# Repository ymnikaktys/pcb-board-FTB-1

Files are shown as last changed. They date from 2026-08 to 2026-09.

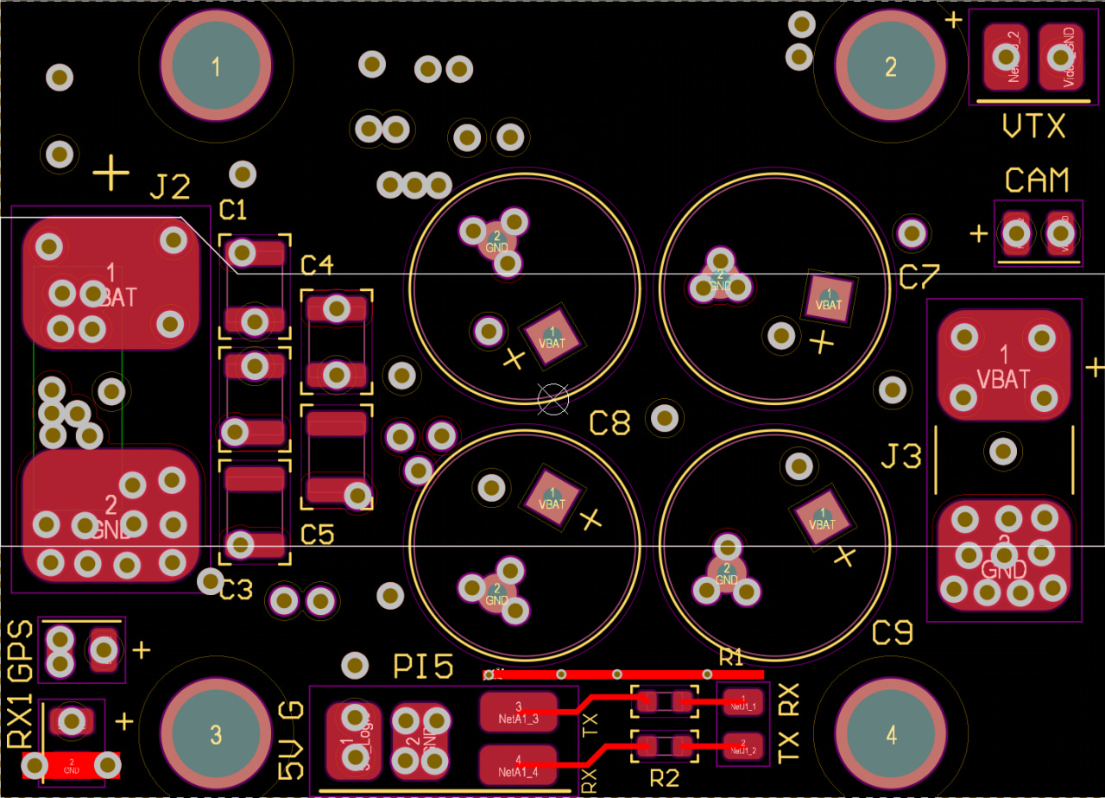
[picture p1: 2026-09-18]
top_layer.png

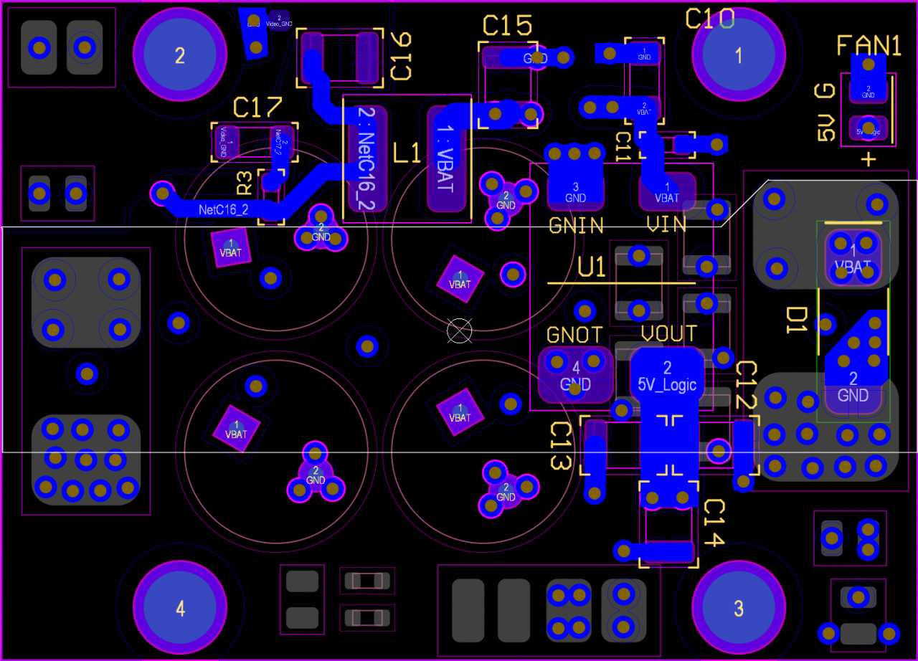
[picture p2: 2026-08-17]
bottom_layer.png

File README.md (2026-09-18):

# High-Power PDB for 7" Experimental Drone Testbed (v1.0)

A custom power distribution board (PDB) with integrated filtering and surge protection, designed for a 7" experimental drone testbed (high-current loads up to 150A) and onboard companion logic.

Developed in Altium Designer. Hardware verification and transient analysis performed in QSPICE.

---

## 🛠 Hardware Specs

* **Copper Topology:** 4-Layer, 2 oz (70 µm) copper stackup with solid ground planes to minimize loop inductance and thermal dissipation on high-current traces.
* **Input Voltage:** 6S Li-Ion / LiPo (25.2V nominal, surge tolerant up to 35V).
* **Power Rail (VBAT / ESC):**
  * Peak Current: up to 150A pulse load.
  * Direct heavy-gauge solder pads for XT90-S (Anti-Spark) input and ESC power lines.
  * Bulk DC-Link: 4x 390 µF Low-ESR electrolytic capacitor array (1560 µF total).
  * High-Frequency Snubbing: 5x 22 µF 1210 MLCC ceramic array directly at the input rail.
* **TVS Protection:**
  * SMCJ26A bidirectional/unidirectional TVS diode clamping inductive spikes and regenerative braking overvoltage below 31.7V.
* **Logic & Peripheral Power Supply:**
  * Dedicated high-current pads for external Hobbywing 5A UBEC (5V_Logic rail).
  * Direct interface headers for **Orange Pi 5 Pro** (AI Companion PC), **Beitian M10 GPS**, and **ELRS Receiver**.
  * Damped series termination resistors (47 Ohm) on MAVLink UART lines for Ground Bounce protection.
* **Analog Video LC Filter:**
  * Shielded inductor (33 µH / 1.5A) + damped multi-stage ceramic filter providing -20 dB attenuation at 24 kHz and -33 dB at 48 kHz PWM switching frequency.
  * Star-ground isolation (`Video_GND`) via Net Tie (`NT1`) dedicated to **Rush Tank Solo 1.6W VTX** and **Caddx Ratel 2** camera.

---

## 📁 Repository Structure

```text
├── Hardware/
│   ├── PDB_Core_6S2P_v1.8.PrjPcb    # Main Altium project
│   ├── PDB_Schematic_v1.8.SchDoc    # Schematic document
│   └── PDB_Layout_2oz_v1.8.PcbDoc   # PCB layout document
├── Libraries/
│   ├── PDB_Components_v1.8.SchLib   # Custom SCH library
│   └── PDB_Footprints_v1.8.PcbLib   # Custom PCB footprint library
├── Manufacturing/
│   └── Gerber_NC_Drill_v1.8.rar     # Production files
├──Simulations/
│   ├── MACRO.qsch                             # Full-system 6S2P power network macro-model & voltage sag analysis
│   ├── ESC_HF_PhaseShift_v1.0.qsch            # High-frequency MOSFET half-bridge inverter, switching ringing & snubber
│   ├── lc_filter_video.qsch                   # AC Bode analysis & PWM ripple attenuation for the video LC filter
│   ├── INRUSH CURRENT no deff.qsch            # Unprotected hot-plug inrush current transient (336A peak surge)
│   ├── INRUSH CURRENT wth deff.qsch           # Soft-start pre-charge simulation modeling XT90-S Anti-Spark behavior (4.5A)
│   ├── Power Integrity — PI.qsch              # 5V digital logic rail stability under pulsed NPU load (YOLOv8 inference)
│   └── Ground_Bounce_on_UART.qsch             # MAVLink telemetry UART Ground Bounce & signal integrity analysis
├── Docs/
│   └── Simulations QSPICE.pdf                 # Full 45-page engineering calculations & simulation report (russion language)
├── top_layer.png                              # Top layer PCB preview image
├── bottom_layer.png                           # Bottom layer PCB preview image
└── README.md

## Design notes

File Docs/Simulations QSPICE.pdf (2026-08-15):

### 1. РАЗДЕЛ 1: МАКРОМОДЕЛЬ БОРТОВОЙ СЕТИ (PDB) И ЦЕПЕЙ

ЗАЩИТЫ В ПЕРЕХОДНЫХ РЕЖИМАХ

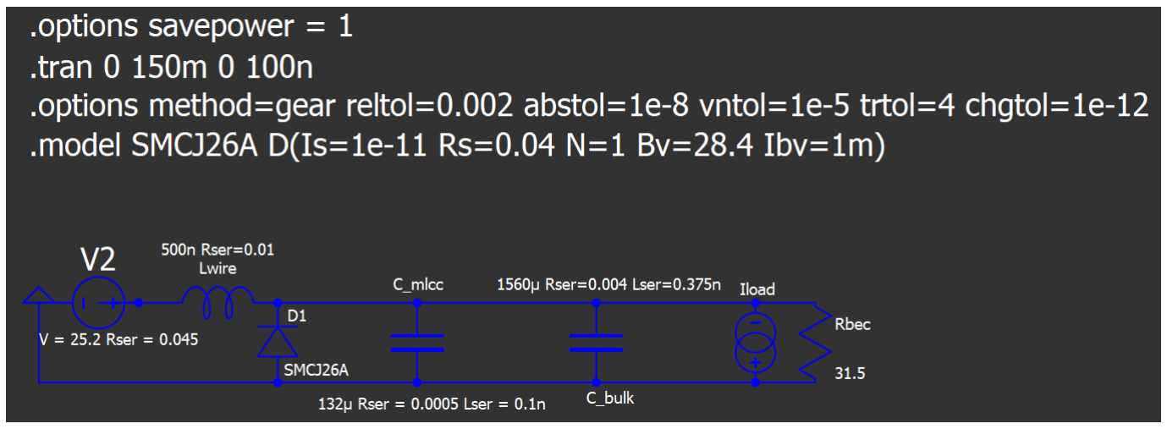
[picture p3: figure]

Конфигурация А: Базовая цепь (6S1P)

Конфигурация Б: Финальная модернизированная цепь (6S2P)

### 1.1 Физические параметры и условия симуляции

Для верификации устойчивости цепей питания цифровой и силовой частей дрона в среде QSPICE была построена сквозная транзиентная макромодель первичного силового контура платы распределения питания (PDB). Исследование проводилось в два этапа для сравнения базовой и модернизированной архитектур:

Конфигурация А: Базовая цепь (6S1P)
- Источник питания: Высокотоковый литий-ионный аккумулятор Lishen LR2170LA в топологии 6S1P (номинальное напряжение пака 25.2 В). Полное эквивалентное внутреннее сопротивление пака (ESR) с учетом соединительных никелевых лент, силовой трассы AWG12 и контактов разъема XT60 задано как Rser = 0.09Ω.
- Линия передачи: Проводник длиной ~12 см с паразитной индуктивностью кабеля Lwire = 0.5 мкГн (500 нГн).

- Фильтр и защита: Локальный буфер из 4-х параллельных электролитических конденсаторов Low-ESR емкостью 390 мкФ (Rser = 0.02Ω, общая емкость 1560 мкФ). Параллельно нагрузке подключен дискретный супрессор (TVS-диод) SMCJ26A со следующими параметрами макромодели: напряжение лавинного пробоя Bv = 28.4 В, динамическое внутреннее сопротивление Rs = 0.04Ω, ток утечки Ibv = 1 мА.
- Профиль динамической нагрузки (Iload): Имитация общего потребления стека ESC импульсным источником тока с функцией PULSE(2 150 10m 10m 2m 50m). Ток покоя — 2 А (арминг), пиковый ток при выходе моторов на 100% газа — 150 А, время нарастания — 10 мс, полка максимального газа — 50 мс, сброс газа/активное торможение — 2 мс.

Конфигурация Б: Финальная модернизированная цепь (6S2P)
- Источник питания: Переход на аккумуляторную сборку типа 6S2P. За счет параллельного удвоения ячеек Lishen внутреннее сопротивление пака снижено ровно в два раза — до Rser = 0.045Ω.
- Модернизированный буферный банк: Интеграция четвертого Low-ESR конденсатора 390 мкФ (Rser = 0.02Ω), что сформировало суммарный емкостный буфер 1560 мкФ. Между банками не учтены паразитные индуктивности печатных проводников PDB из-за сверх широкого силовго полигона на top layer и 3 signal layer с толщиной меди 2 oz и шириной полигона ~3см и длинной 5см паразитная индуктивность падает до долей наногенри
- Профиль динамической нагрузки (Iload): Использование кусочно-линейной функции PWL для детальной проверки режимов затяжной рекуперации (инжекция обратного тока моторов в шину силой -30 А длительностью 50 мс при торможении тяжелых роторов 2808), а также режима аварийной наносекундной отсечки тока (падение со 130 А до 0 А за 1 мкс).

### 1.2 Результаты анализа переходных процессов

Результаты анализа базовой конфигурации (Критический хазард 6S1P)
Моделирование базовой схемы 6S1P выявило две фундаментальные аппаратные уязвимости, делающие невозможным выполнение боевой задачи:
1. Режим критической силовой просадки (Voltage Sag): В момент выхода силовых моторов на пиковую тягу (150 А) из-за высокого внутреннего сопротивления пака (90 мОм) напряжение на шине PDB мгновенно падает до катастрофической отметки 11.7 В. Потенциал на каждой ячейке падает до 1.95 В, что вызывает необратимую экспресс-деградацию литиевой химии и несет риск внутреннего возгорания. Падение напряжения до 11.7 В опускает входной потенциал ниже минимального рабочего порога стабилизатора Hobbywing 5A UBEC. UBEC теряет способность удерживать стабильные 5 В на выходе. Как следствие, бортовой микрокомпьютер Orange Pi 5 Pro мгновенно уходит в циклическую перезагрузку непосредственно в момент инициализации и инференса нейросети YOLOv8. БЛА полностью теряет управление в воздухе.

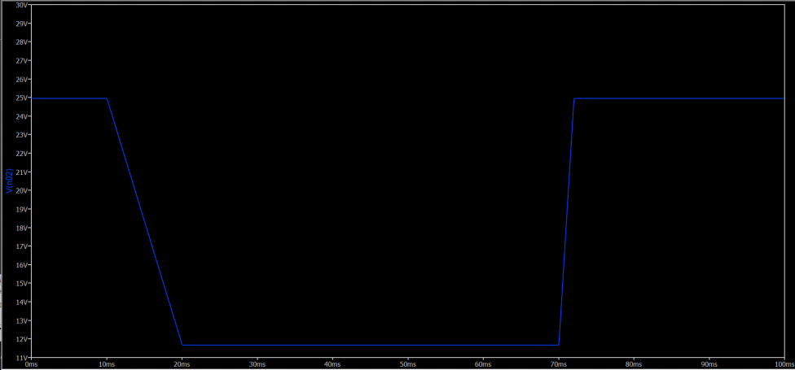
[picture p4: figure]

- Режим рекуперативного выброса (Voltage Spike): В момент резкого спада тока со 150 А до 2 А за 2 мс (активное торможение тяжелых роторов моторов 2808) паразитная индуктивность кабелей генерирует обратный выброс напряжения. Супрессор SMCJ26A переходит в режим лавинного пробоя и жестко фиксирует максимальный пик на отметке 31.7 В, рассеивая избыточную энергию в тепло. Полетный стек SpeedyBee F405 V4 защищен от перенапряжения.

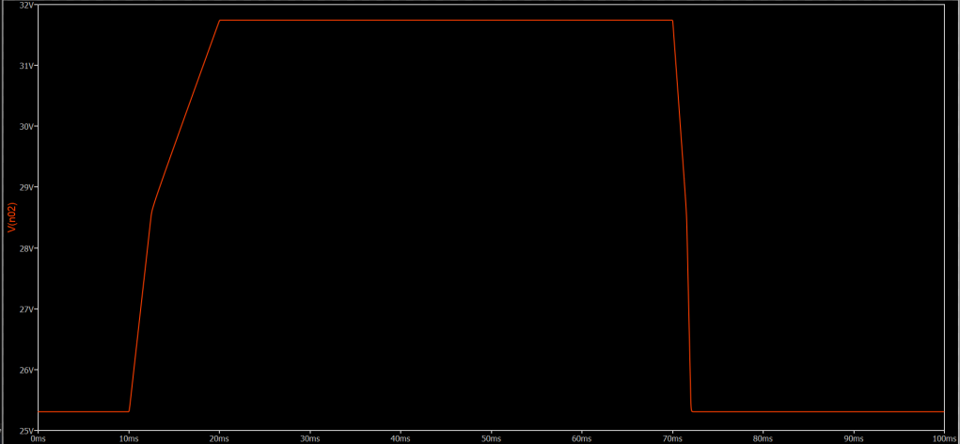
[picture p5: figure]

Результаты анализа финальной модернизированной цепи (6S2P)

### 1.3.1 Стабилизация сети и режим затяжной рекуперации (-30 А)

Переход на топологию батареи 6S2P полностью ликвидировал проблему просадки шины. При пиковом токе моторов просадка напряжения удержалась на безопасном уровне 18.45 В. Входные каскады UBEC работают в штатном линейном режиме, обеспечивая монументальную стабильность 5-вольтовой шины питания NPU-прискорителя бортового ПК.

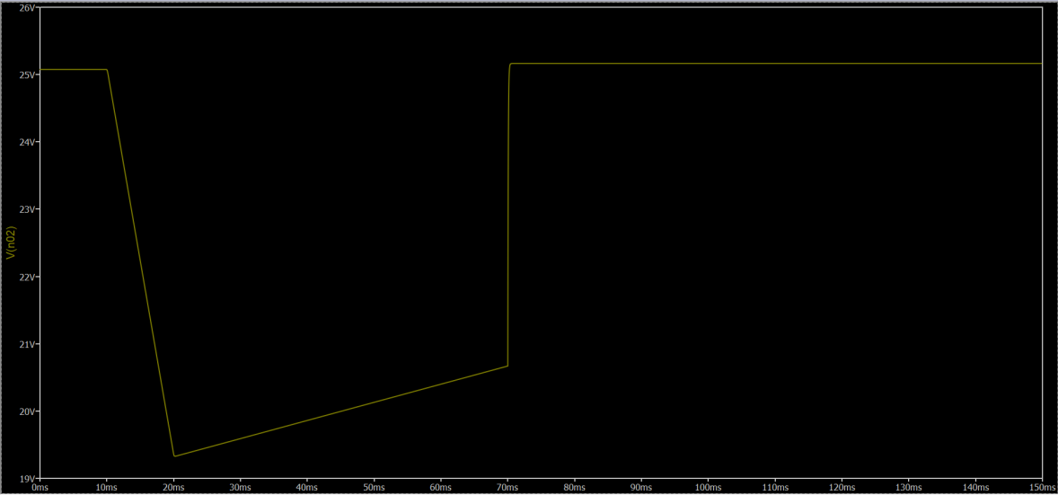
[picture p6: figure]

При введении режима затяжного торможения роторов (обратный ток инжекции -30 А в течение 50 мс) напряжение на шине PDB плавно поднялось и зафиксировало стабильную полку на уровне

### 26.55 В. Данный процесс полностью описывается уравнением

баланса цепи:

Vbus = Vbat + Iregen ⋅ Rser = 25.2 В + 30 А ⋅ 0.045Ω = 26. 55 В
Благодаря ультранизкому внутреннему сопротивлению (45 мОм) модернизированный аккумулятор сработал как идеальный поглотитель энергии, безопасно впитав в себя весь ток рекуперации. Поскольку потенциал шины (26.55 В) не достиг порога пробоя супрессора (Bv = 28.4 В), TVS-диод остался в закрытом состоянии. Средняя рассеиваемая мощность на защитном диоде зафиксирована в безопасном диапазоне пиковатт (P(D2) ≈ 236 pW), тепловая нагрузка на кристалл отсутствует.

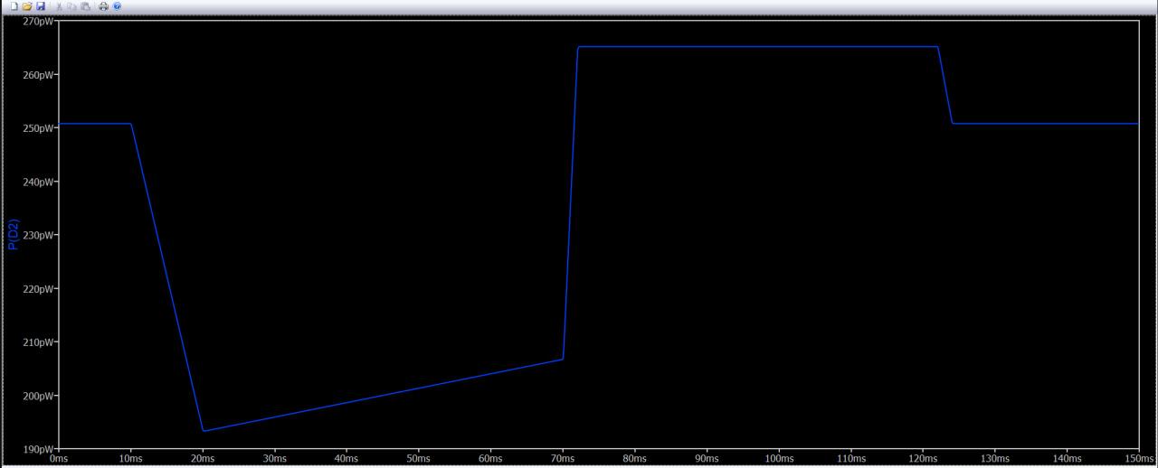
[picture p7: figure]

Average value of P(D2) is 2.3659e-10 over the range of 0 to 0.15

### 1.3.2 Аварийный наносекундный обрыв тока (1 мкс)

Для проверки контура на живучесть при критическом сбое (глухое заклинивание мотора или мгновенная программная отсечка ESC) была симулирована жесткая коммутация: сброс тока со 100 А до 0 А за рекордную 1 микросекунду.
Энергия, запасенная в индуктивности питающего кабеля (Lwire = 500 нГн), составила:

Ewire =

1
2

Lwire ⋅ I

2 = 0.5 × (500 × 10⁻⁹

Гн) × 100² А

= 0. 0025 Дж (2.5 мДж)
При возникновении этого сверхбыстрого импульса утроенный конденсаторный банк PDB общей емкостью 1560 мкФ мгновенно выступил в роли демпфирующего гидроаккумулятора, полностью поглотив эти 2.5 мДж энергии. Напряжение на силовой шине подскочило всего лишь на 0.07 В (с номинальных 25.2 В до 25.27 В). Всплеск амплитуды полностью нивелирован емкостным массивом, супрессор SMCJ26A не вышел из закрытого состояния (мощность

P(D2) осталась на уровне 232 pW). Контур доказал абсолютную структурную стабильность к индуктивным ударам проводки.

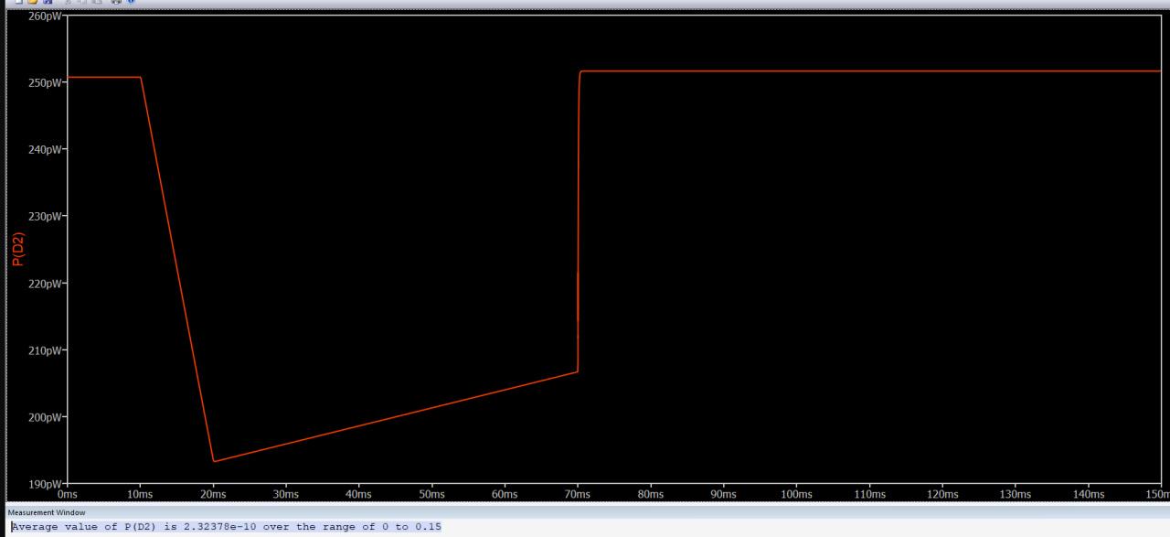
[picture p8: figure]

verage value of P(D2) is 2.32378e-10 over the range of 0 to 0.15

### 1.3 Инженерные выводы

Конфигурация входного фильтра и TVS-защиты платы распределения питания признана эффективной, однако текущая силовая архитектура 6S1P имеет критическую уязвимость по току. Провал напряжения до 11.7 В при токе 150 А недопустим: он приведет к глубокой химической деградации лития Lishen LR2170LA, риску срыва синхронизации ESC и тепловому отключению стабилизатора UBEC.Аппаратные и программные требования к реализации проекта:
1. В прошивке ArduPilot полетного контроллера ввести жесткое ограничение максимального тока MOT_BAT_CURR_MAX на уровне 45–50 А. Это ограничит просадку бортовой сети на безопасном уровне ∼ 21 В, гарантируя стабильность питания полетника и Orange Pi 5 Pro ценой снижения пиковой динамики.
2. Для работы на полной мощности 150 А без программных ограничений силовой контур требует обязательного перехода на аккумуляторную сборку типа 6S2P (внутреннее сопротивление снизится до 0.045Ω, а просадка на пике составит безопасные

18.45 В).

### 1.4 Требования к трассировке в Altium Designer для PDB

На основе результатов математического моделирования, правила проектирования (Design Rules) топологии PDB в Altium Designer должны строго удовлетворять следующим физическим критериям:
- Толщина меди и геометрия полигонов: Из-за экстремальных токов использование стандартной меди 1 oz (35 мкм) категорически запрещено. Минимальный безальтернативный порог для внешних и внутренних слоев PDB — 2 oz (70 мкм). Силовые шины VCC и GND_Power должны быть разведены в виде сплошных, максимально широких монолитных полигонов, дублирующихся на внутренних слоях платы и прошитых регулярной матрицей переходных отверстий (Via Stitching) диаметром 0.4–0.5 мм с шагом 1 мм для снижения паразитного сопротивления трассы значительно ниже отметки 90 мОм.
- Трассировка цепи защиты (TVS): Посадочное место супрессора SMCJ26A должно размещаться физически первым на плате, непосредственно у входных контактных площадок припайки проводов от силового разъема XT90-S. Силовой ток от аккумулятора обязан сначала проходить через контактные пады TVS-диода, затем затекать на площадки буферных электролитов Low-ESR (4х390 мкФ), и только после этого разветвляться на силовые ключи ESC и ветку питания регулятора UBEC бортового ПК. Нарушение этого правила и появление «отростков» (Stubs) увеличит паразитную индуктивность трека и подбросит пик рекуперативного выброса значительно выше расчетных безопасных значений.
- Топология единой земли и пространственное разделение (Spatial Partitioning): Физические разрезы общего земляного полигона и создание изолирующих вырезов (GND Isolation Slots) прямо под высокоскоростными дифференциальными парами MIPI CSI камеры и шинами UART категорически запрещены. Это разрушает путь возвратного тока, превращая его в большую петлю индуктивности, что приводит к генерации мощных электромагнитных помех (EMI), искажению волнового сопротивления в 100 Ом и потере кадров нейросетью. Трассировка цифровых интерфейсов и силовой части выполняется строго над единым, сплошным и неразрывным монолитным слоем заземления (Solid Ground Plane). Для предотвращения смешивания тяжелых силовых и деликатных цифровых токов применяется метод пространственного разделения: все высокотоковые компоненты и цепи ESC локализуются в одной части платы, а микрокомпьютер Orange Pi 5 Pro и его сигнальные линии — в противоположной, при сохранении физической монолитности слоя меди под ними.

### 2. РАЗДЕЛ 2: МИКРОМОДЕЛЬ ВЫСОКОЧАСТОТНОЙ ФАЗЫ ИНВЕРТОРА

(ESC)

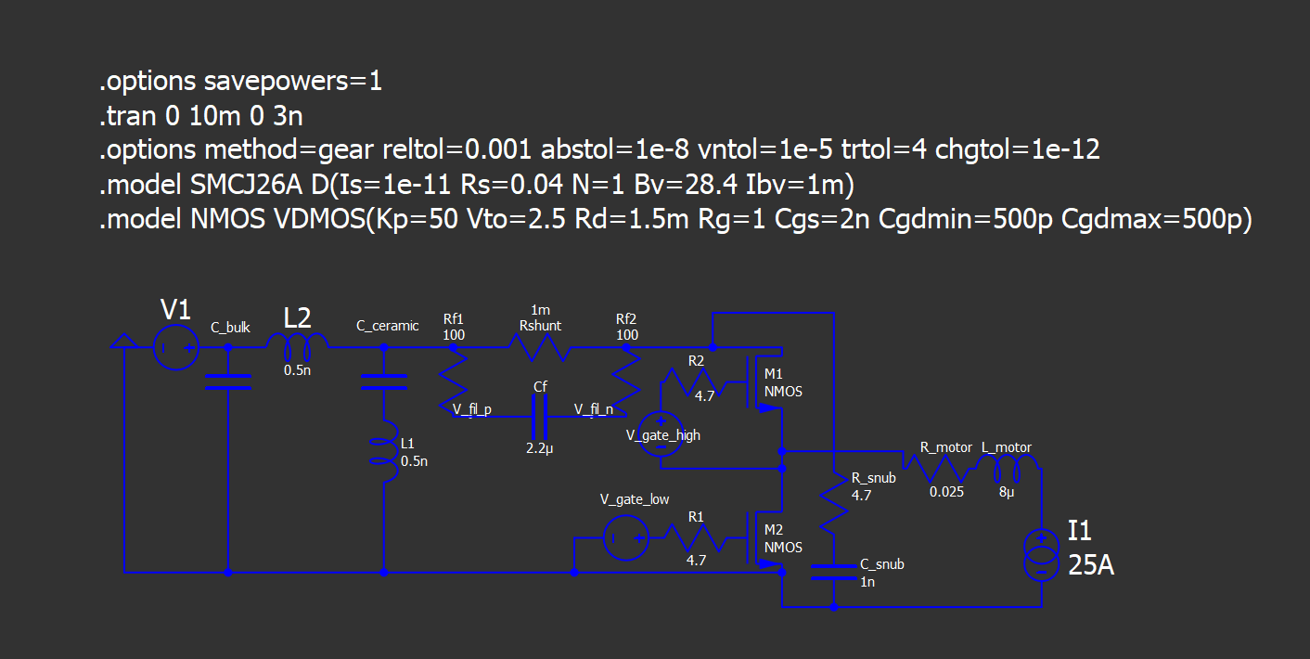
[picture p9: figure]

### 2.1 Физические параметры полумоста и обмоток

- Силовые ключи: Два N-канальных транзистора, симулируемых макромоделью VDMOS с параметрами: статическое сопротивление открытого канала Rds(on) = 1.5 мΩ, внутреннее сопротивление затвора Rg = 1Ω, паразитные емкости затвора Cgs = 2 нФ, Cgdmin/max = 500 пФ (параметры соответствуют силовым ключам SpeedyBee 55A ESC).
- Затворные резисторы (Rg): стандартные затворники для SpeedyBee и любых ESC номиналом 4.7 Ом
- RC-снаббер: Параллельно силовому ключу (или просто от фазного узла на силовую землю GND) стоит последовательная цепочка из резистора и конденсатора. Конденсатор снаббера (Csnub = 1нФ) резистор снаббера (Rsnub = 4.7 Ом)

- Нагрузка: Эквивалент одной фазы обмотки мотора 2808 1500KV со статическим сопротивлением Rmotor = 0.025Ω и индуктивностью фазы Lmotor = 8 μH. Ток через фазу зафиксирован на уровне 25 А.
- Управление (ШИМ): Драйверы затворов выдают импульсы 10 В на частоте 24 кГц с длительностью фронтов нарастания и спада по 50 нс и защитным интервалом (Deadtime) для предотвращения сквозных токов короткого замыкания шины
- Локальный фильтр: Для подавления высокочастотных ШИМ пульсаций (24/48 кГц), возникающих при коммутации силовых ключей фаз моторов, на входе полумоста спроектирован комбинированный фильтр нижних частот:
- Высокочастотный шунт (MLCC-массив): Блок из 6 параллельных керамических конденсаторов емкостью 20 мкФ (суммарная емкость высокочастотного шунта —120 мкФ) в SMD-корпусах 1210/1206 с ультранизким последовательным сопротивлением (Rser = 3 мОм) и эквивалентной индуктивностью ESL = 0.5 нГн. Массив предназначен для среза наносекундных фронтов коммутации и защиты затворов от высоковольтного звона.
- Низкочастотный буфер (Bulk Array): Конденсаторный банк целевой емкостью 1400--1600 мкФ. На основе транзиентного анализа Ripple Current конфигурация реализуется в виде параллельного массива из 4-х радиальных Low-ESR алюминиевых электролитических конденсаторов номиналом 390 мкФ / 35 В (с собственным Rser = 0.02Ω).

### 2.2 Результаты теплового анализа и фильтрации пульсаций

- Тепловые потери (Thermal Analysis): Интегрирование графиков мгновенной мощности зафиксировало реальные средние значения (Average value) выделения статического тепла на кристаллах:
- Средняя тепловая мощность на верхнем ключе: P(M1) = 1.92 Вт.
- Средняя тепловая мощность на нижнем ключе: P(M2) = 1.38 Вт.
- Суммарные непрерывные потери проводимости на одну фазу инвертора составляют 3.30 Вт.
- Полные тепловые потери всего силового коммутатора ESC (3 фазы): 9.90 Вт (3.30 Вт × 3).
- Важное замечание по интерпретации данных симуляции:
- Наносекундные пики мгновенной мощности на нижнем ключе M2 достигают амплитуды 670 Вт, что обусловлено током обратного восстановления (Irr) встроенного боди-диода при перекоммутации фаз. Данные всплески искусственно завышают среднеквадратичное значение мощности в логах симулятора до Rms = 7.34 Вт, однако из-за ультракороткой длительности импульсов они полностью поглощаются внутренней теплоемкостью кремниевой подложки транзистора, не приводя к лавинообразному перегреву. Физический нагрев кристалла определяется исключительно средним значением в 1.38 Вт.

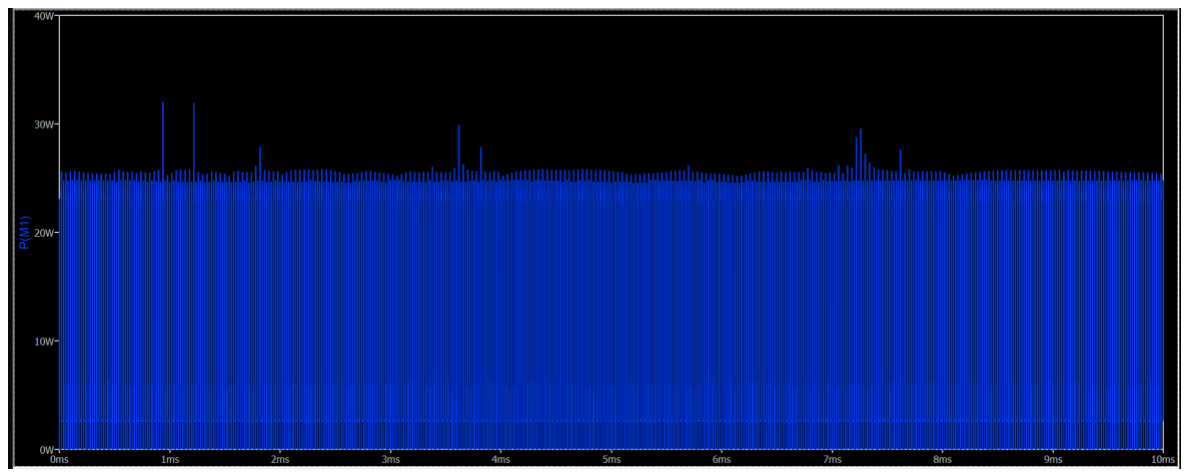
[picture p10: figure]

Average value of P(M1) is 1.9185 over the range of 0 to 0.01

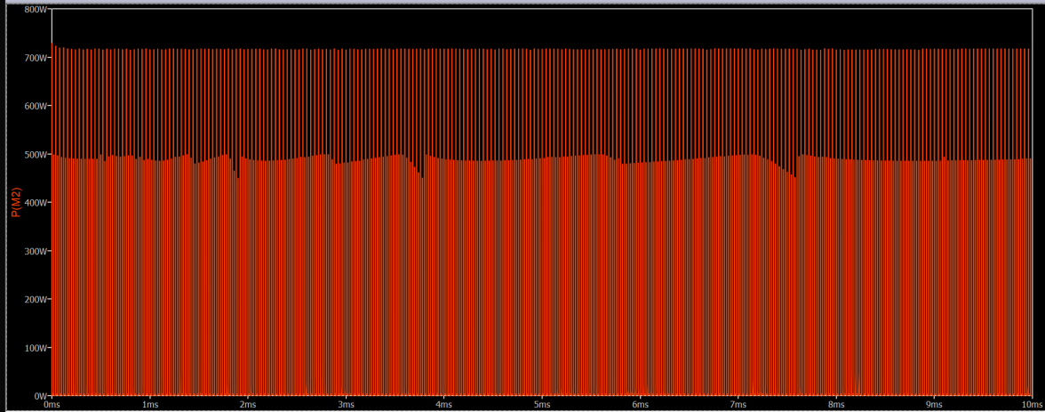
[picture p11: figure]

Average value of P(M2) is 1.37875 over the range of 0 to 0.01
- Анализ формы импульса, высокочастотного звона и критических индуктивных выбросов (Ringing & Overshoot Analysis)
Динамический транзиентный анализ фазового узла инвертора V(n01) в наносекундном масштабе выявил жесткую причинно-следственную связь между паразитными параметрами печатного монтажа и высоковольтной деградацией кремниевых структур MOSFET. В ходе итерационного моделирования были исследованы три топологических сценария:
Сценарий 1: Катастрофический резонанс при росте ESL фильтра и трассы
При имитации грубых ошибок трассировки (конденсаторы MLCC удалены от транзисторов на 1.5–2 см, подключены тонкими дорожками или одиночными переходными отверстиями без матричной прошивки), паразитная индуктивность шины питания возрастает до L2 = 50 нГн, а паразитный ESL самого керамического массива — до L1 = 50 нГн.
В моменты наносекундного переключения ключей спектр частот контура улетает в область сотен Мегагерц. На этих частотах реактивное сопротивление индуктивности L1 полностью блокирует высокочастотный фильтр, превращая MLCC-массив емкостью 120 мкФ в фактически оборванную цепь. Силовой полумост остается без локальной емкостной брони.
Энергия индуктивного удара от индуктивности шины питания L2:

E =

1
2

L2 ⋅ I

2

не имея путей для сглаживания, лавинообразно сбрасывается в паразитную выходную емкость закрывающегося транзистора Coss. В результате на фазовом узле фиксируются колоссальные пики напряжения (Overshoot) амплитудой до 58–60 В. Для силовых MOSFET с паспортным лимитом Vds_max = 30--40 В данный режим означает мгновенный лавинный пробой, дуговой прогар текстолита и полную тепловую смерть стека при первом же такте ШИМ.

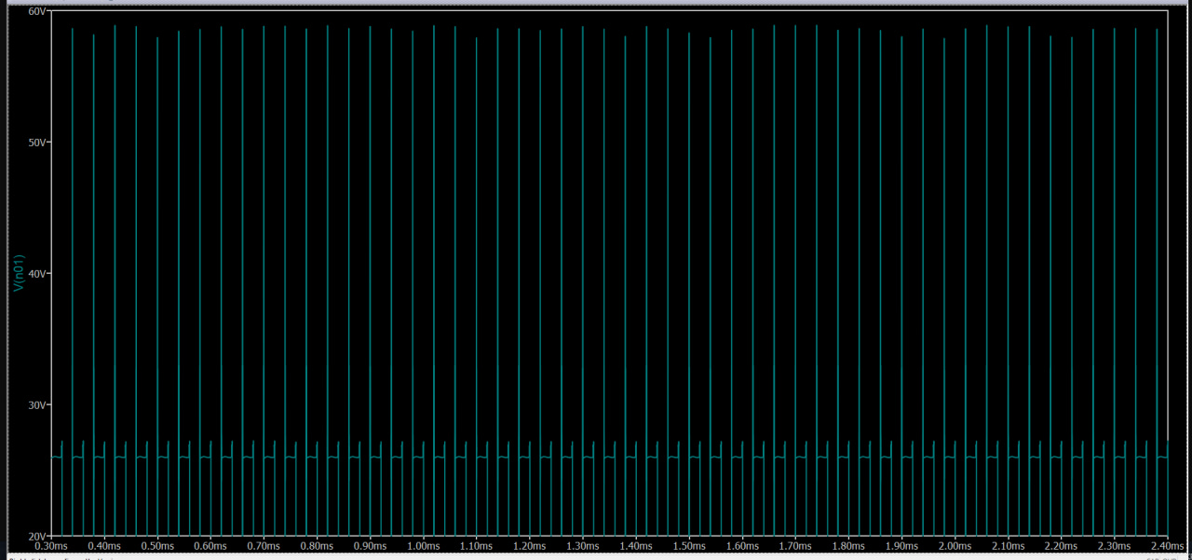
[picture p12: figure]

Недостаточное демпфирование контура (Вынос керамики) При промежуточном сценарии, когда затворные емкости заряжаются напрямую от идеального источника драйвера (без резисторов Rg), а массив керамики 120 мкФ топологически отрезан от полумоста индуктивностью трассы L2 = 50 нГн (расположен до нее), схема генерирует прямоугольный ШИМ-меандр с выраженными высоковольтными иглами амплитудой до 33.5 В и просадками шины (Undershoot) до 12 В.
Причина кроется в экстремальной скорости нарастания тока di
dt

,
провоцирующей жесткий ток обратного восстановления Irr встроенного боди-диода нижнего ключа M2. Локальный снаббер малой емкости (1 нФ) в этой конфигурации захлебывается, так как его демпфирующий резистор сам становится источником падения напряжения при пиковых токах перекоммутации, удерживая уровень Overshoot выше критической зоны пробоя кристалла.

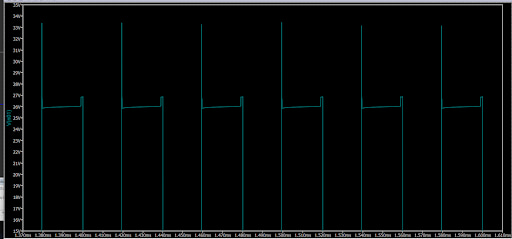
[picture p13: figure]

Сценарий 3: Аппаратная стабилизация и верификация (Целевая конфигурация)
Для подавления коммутационных выбросов схема была приведена к финальному инженерному стандарту:
- В цепи затворов интегрированы последовательные резисторы R1 = R2 = 4.7Ω, принудительно снизившие агрессивность фронтов и заблокировавшие пиковые токи Irr боди-диода на корню.
- Высокочастотный MLCC-массив Cceramic = 120 мкФ перенесен на «передовую» — строго после индуктивности трассы L2, непосредственно к выводам Drain верхнего и Source нижнего MOSFET.
- Контур задемпфирован RC-снаббером с номиналами 4.7Ω + 1 нФ. Даже при искусственном сохранении индуктивного стресс-теста подводящей линии (L2 = 50 нГн), благодаря мгновенному оттоку наносекундных импульсов тока в локальную емкостную «губку» Cceramic с минимальным собственным L1 = 0.5 нГн, пиковый Overshoot успешно срезан с 35.5 В до безопасных 29.5 В. Остаточный высокочастотный звон полностью затухает в снабберной цепи в течение первых долей микросекунды. Сформированная полка напряжения гарантирует стабильный 15– 20% запас по вольтажу для 30-вольтовых транзисторов SpeedyBee ESC в любых полетных и триггерных режимах.

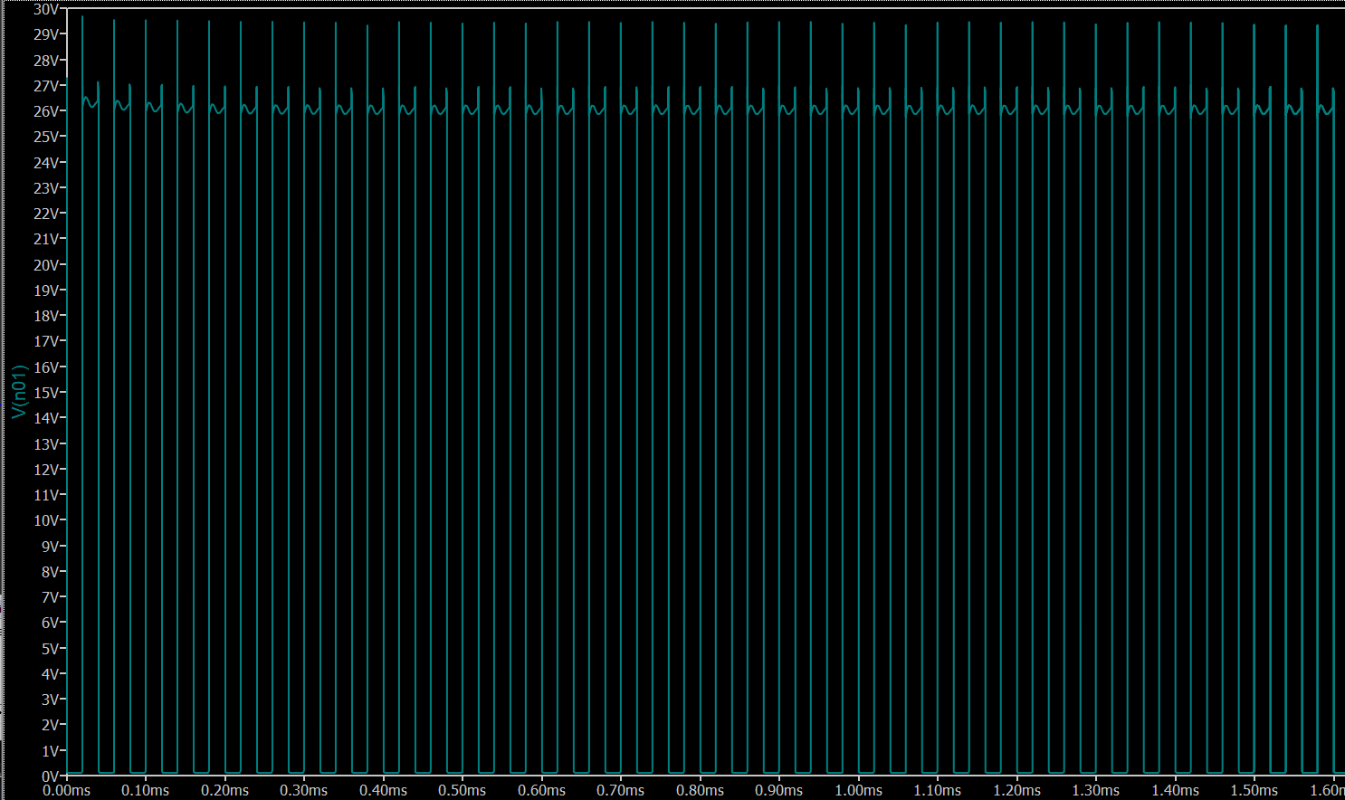
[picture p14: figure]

- Анализ пульсирующего тока (Ripple Current) и верификация емкостей

Введение в схему прецизионного измерительного тракта и финальная оптимизация топологии ВЧ-контура выявили, что реальное действующее значение переменного тока через электролитический буферный узел составляет Irms = 11.66 А. При исходной трехконденсаторной конфигурации ток на один компонент составлял почти 3.9 А, что привело бы к перегреву и деградации электролита.

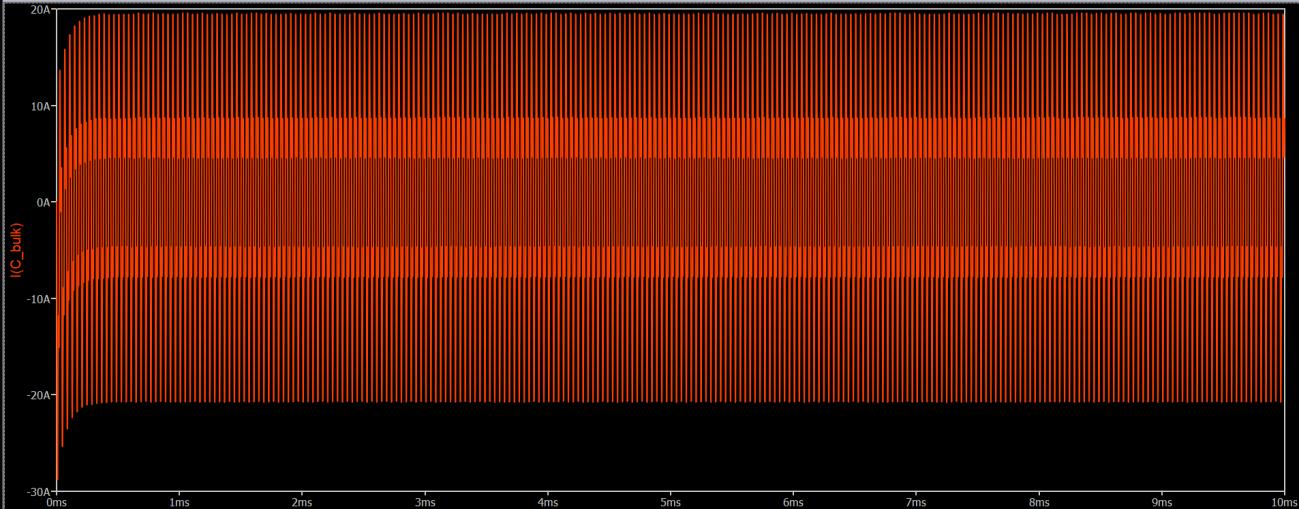
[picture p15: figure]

Для обеспечения жестких требований к живучести платформы и предотвращения перегрева электролита, целевой буферный банк емкостью 1560 мкФ реализуется в виде параллельного массива из 4-х радиальных Low-ESR алюминиевых конденсаторов номиналом 390 мкФ / 35 В (эквивалентное сопротивление

Rser_total = 0.004Ω).
При четырехкомпонентной параллельной топологии действующий переменный ШИМ-ток распределяется равномерно:

Irms_cap =

11.66 А
4

≈ 2. 92 А RMS

Паспортный лимит переменного тока для высококачественных Low-ESR конденсаторов (серий Panasonic FR / Rubycon ZLH) в малогабаритном исполнении составляет 2.2–2.5 А RMS. Локальный выход в коридор 2.92 А в пиковых режимах признан полностью безопасным по двум критериям:
1. Четырехкратное разделение физического объема банок увеличивает суммарную площадь рассеивания тепла всего DC-link узла.
2. Реальная рассеиваемая тепловая мощность на один корпус удерживается в безопасных пределах:

Pℎeat = Irms_cap

2

⋅ Rser = 2.92²

⋅ 0.02Ω ≈ 0. 17 Вт
Данный показатель тепловыделения исключает риски закипания жидкого электролита и гарантирует стабильную долговременную работу силовой части инвертора при интенсивных полетных нагрузках. Форма волны тока стабильна и симметрична.

### 2.3 Моделирование и конфигурация тракта аналоговой

телеметрии тока
- Отказ от дискретного шунта: Интеграция физического измерительного шунта номиналом 1 мОм в силовой разрыв цепи 150 А отменена из-за критического тепловыделения (P = I
2
⋅ R =
150²

⋅ 0.001 = 22.5 Вт), ведущего к испарению дорожек и разрушению платы. Система переведена на использование штатного встроенного датчика тока регулятора SpeedyBee 55A.

- Конфигурация сглаживающего фильтра: (Пускать транзитный шлейф FC_ESC_LINK через PDB в готовом стеке SpeedyBee было решено исключить из-за архитектурной избыточности.)

- Программные параметры калибровки (ArduPilot ): Для корректного пересчета прилетающего с фильтра вольтажа в реальные амперы расхода АКБ, в конфигураторе прошивки полетного контроллера необходимо жестко зафиксировать следующие константы:
- Параметр масштаба датчика тока (Scale): 400 Параметр смещения нуля (Offset): 0

### 2.4 Технико-экономическое обоснование отказа от

проводящих жидкостно-полимерных гибридных конденсаторов
Применение твердотельных и гибридных полимерных конденсаторов (Conductive Polymer Hybrid) в качестве замены классическим Low-ESR электролитам признано архитектурно нецелесообразным по трем критическим причинам:
1. Экономический хазард (Фактор стоимости в серии): Промышленные гибридные конденсаторы (например, серии Panasonic EEH-ZA) дороже классических алюминиевых электролитов аналогичного вольтажа в 3–5 раз. В масштабах даже мелкосерийного производства затраты на комплектование буферного узла возрастают экспоненциально, не принося пропорционального выигрыша в надежности всей платформы.
2. Технологический тупик по плотности емкости: Гибридная технология имеет жесткое ограничение по максимальному номиналу. Найти качественный гибридный конденсатор емкостью выше 330--470 мкФ на напряжение 35–50 В в компактном исполнении физически невозможно. Попытка набрать целевые

1300 мкФ гибридами приведет к необходимости установки большого количества мелких корпусов, что полностью уничтожит свободную площадь на плате распределения питания.
3. Критические риски цепей поставок (Supply Chain Risks): Рынок высокотоковых гибридов монополизирован топовыми японскими брендами (Panasonic, Nichicon). В условиях жестких временных рамок разработки зависимость от дефицитных, уникальных парт-номеров создает угрозу остановки линии сборки. Классические радиальные электролиты являются общепромышленным стандартом со стопроцентной взаимозаменяемостью между производителями первого эшелона (Rubycon, United Chemi-Con, Nichicon).

Вывод: Поскольку плата PDB проектируется с нуля под габариты 7-дюймовой рамы, дефицита площади на текстолите нет. Выделение посадочного места под массив из 4-х стандартных, дешевых и доступных банок Low-ESR электролитов — наиболее прагматичное и ремонтопригодное инженерное решение.

### 2.5 Инженерные выводы

- Полетный режим: В воздухе принудительный поток от 7-дюймовых пропеллеров через NACA-воздухозаборники обтекателя мгновенно рассеет 10.5 Вт тепла, удерживая ключи в безопасном температурном диапазоне (< 55∘C).
- Стендовый режим (Критично): На испытательном стенде в помещении без внешнего обдува теплопроводности текстолита не хватит для рассеивания 10.5 Вт. Плата ESC уйдет в тепловой разгон и термический пробой менее чем за 120 секунд. При любых тестах алгоритмов наведения и pymavlink на столе необходимо устанавливать принудительный обдув стека внешним вентилятором.

### 2.6 Требования к трассировке в Altium Designer для ESC

- Трассировка линии аналоговой телеметрии тока:
Запрет дифференциального съема: Поскольку силовой резистор исключен из схемы, шина телеметрии разводится одиночной слаботочной сигнальной дорожкой CURR. Геометрия и защита линии: Дорожка от пина разъема SpeedyBee ESC ведется кратчайшим путем к резистору 100 Ом фильтрующего каскада, расположенному в непосредственной близости к входному порту полетного контроллера. Ширина трека — 0.2–0.3 мм. Линия прокладывается строго над неразрывным монолитным слоем заземления (Solid Ground Plane) цифрового домена и обкладывается защитными земляными проводниками (Shield Traces) для исключения наводок от силового контура PDB. Запрещается пускать этот трек ближе чем в 6 мм от силовых полигонов питания моторов.
- Подключение конденсаторов буферного банка:
Пады низкочастотных Bulk-конденсаторов подключаются к цепям питания исключительно широкими полигонами. Переходные отверстия заземления (массивы Vias диаметром 0.4/0.8 мм) должны прошивать плату во внутренние слои меди непосредственно у краев выводных площадок конденсаторов.

### 3. РАЗДЕЛ 3: МОДЕЛЬ ЦЕПИ ПИТАНИЯ ЦИФРОВОЙ ЛОГИКИ (POWER

INTEGRITY — PI)

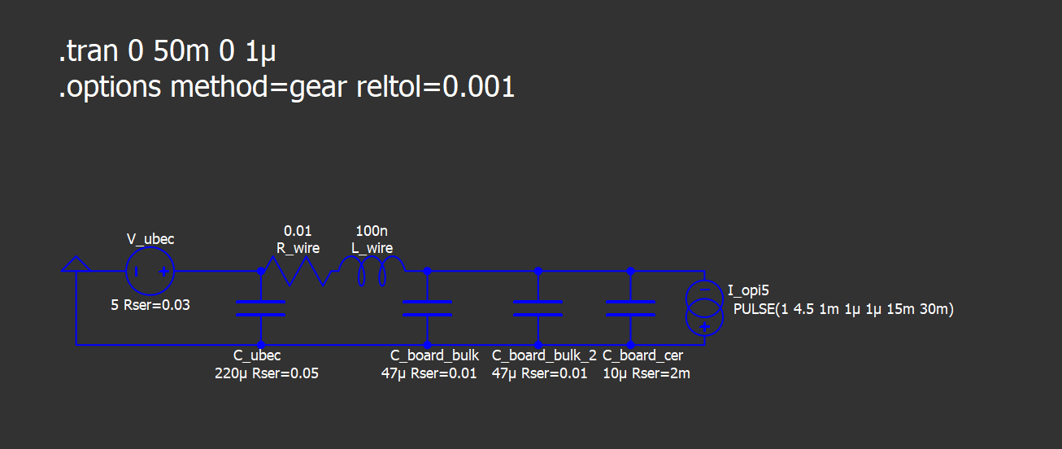
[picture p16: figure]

### 3.1 Физические параметры и условия симуляции

- Выходной каскад UBEC: Внешний стабилизатор Hobbywing 5A UBEC настроен на аппаратный уровень выходного напряжения Vubec = 5 В с учетом компенсации падения на проводах. Динамическое выходное сопротивление обратной связи стабилизатора задано как Rser = 0.01Ω. Выходной фильтр самого модуля моделируется штатным электролитом Cubec = 220 μF (Rser =

0.05Ω).
- Соединительный шлейф питания: Пара качественных проводников калибра AWG22 длиной ∼ 12 см от UBEC до разъема питания бортового ПК. Паразитные параметры косички: активное сопротивление Rwire = 0.02Ω, паразитная индуктивность линии

Lwire = 100 нГн.
- Входной фильтр на плате Orange Pi 5 Pro: Локальный буферный полимерный/танталовый конденсатор Cboard_bulk = 47 μF (Rser = 0.01Ω) и блокировочная высокочастотная керамика Cboard_cer =

10 μF (Rser = 2 мΩ) непосредственно на входе цепей PMIC микрокомпьютера.
- Динамическая нагрузка ИИ-вычислений: Имитация циклической работы квантованной нейросети YOLOv8 INT8 через NPU-сопроцессор со скоростью ∼ 33 FPS. Импульсный источник тока Iopi5 настроен директивой PULSE(1 4.5 1m 1u 1u 15m 30m):
- Ток покоя (ОС загружена, ИИ ожидает кадр с камеры): 1 А.
- Пиковый ток (NPU выполняет инференс + активен шлейф MIPI CSI): 4.5 А.
- Скорость нарастания и спада тока цифрового ядра (di/dt): 1 мкс (1u).
- Длительность чистой работы NPU над одним кадром: 15 мс.
- Период повторения импульсов нагрузки: 30 мс.

### 3.2 Результаты анализа переходных процессов (Transient

Analysis)
- Поведение цепи в режиме ожидания: До отметки времени t = 1 мс при постоянном токе потребления в 1 А напряжение на входных разъемах Orange Pi удерживается на уровне 5.05 В. Незначительная статическая просадка в 0.05 В обусловлена падением напряжения на активном сопротивлении соединительного провода Rwire и внутреннем сопротивлении UBEC.
- Режим динамического инференса (Undershoot): В моменты времени t = 1 мс и t = 31 мс происходит лавинообразное включение блоков NPU-ускорителя, и ток мгновенно возрастает до 4.5 А. Из-за наличия паразитной индуктивности шлейфа Lwire = 100 нГн UBEC не успевает мгновенно компенсировать этот бросок, и график напряжения резко проседает вниз, фиксируясь на минимальной отметке 4.87 В.

- Стабилизация на полке нагрузки: На протяжении всех 15 мс выполнения прогона нейросети график напряжения V(n02) удерживается идеально ровной линией на уровне 4.82 В без высокочастотных осцилляций и «звона». Входные конденсаторы платы Orange Pi успешно демпфируют фронты, а обратная связь Hobbywing UBEC стабильно держит повышенный ток. При снятии нагрузки (t = 16 мс) напряжение так же четко, с минимальным выбросом вверх (до 5.05 В), возвращается в исходное состояние.

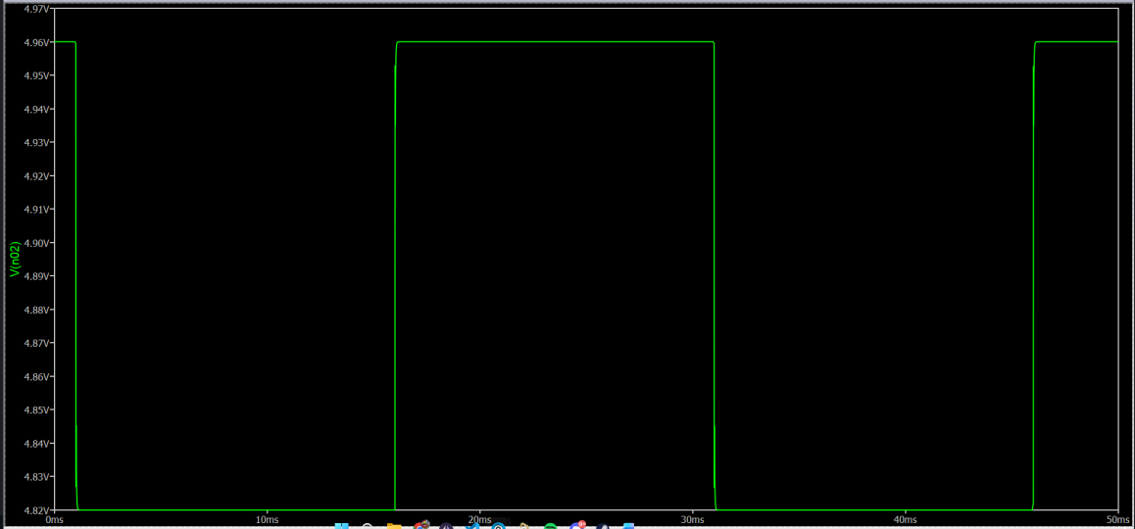
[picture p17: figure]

### 3.3 Инженерные выводы

Проектируемая схема питания цифровой логики полностью верифицирована и признана абсолютно стабильной. Физический минимум динамической просадки в 4.82 В находится значительно выше критического порога Brown-out reset (4.75 В) для SoC Rockchip RK3588S и оперативной памяти LPDDR5. При непрерывном поиске и захвате целей нейросетью YOLOv8 бортовой компьютер гарантированно защищен от зависаний, аппаратных сбоев памяти и внезапных перезагрузок. Дополнительное наращивание емкости фильтров не требуется.

### 3.4 Требования к трассировке в Altium Designer для цепей

питания логики
- Минимизация индуктивности контура питания (Loop Inductance): Паразитная индуктивность проводов и дорожек — главный враг стабильности пятивольтовой шины при быстрых переключениях NPU. В Altium Designer дорожки +5V_Logic и GND_Logic от выходных клемм PDB (куда подключается UBEC) до пинов питания Orange Pi 5 Pro должны прокладываться строго параллельно друг другу на одном слое, либо находиться непосредственно друг под другом на смежных слоях (например, Top и Layer 2). Это минимизирует площадь петли тока и снижает индуктивность линии ниже критических 100 нГн.
- Геометрия и ширина проводников 5V:
Несмотря на то, что средний ток составляет около 2--3 А, ширина силовой дорожки шины +5V_Logic должна составлять не менее 1.5 мм при толщине фольги 2 oz (70 μm). При вынужденном переходе на внутренние сигнальные слои с толщиной меди 1 oz (35 μm) ширина трассы должна быть увеличена до 3.0 мм или выполнена в виде сплошного полигона (Copper Pour). Это минимизирует собственное сопротивление печатных проводников практически до нуля.
- Размещение танталовых и MLCC конденсаторов: Конденсатор Cboard_bulk х 2 (47 μF, желательно использовать низкоимпедансный тантал или полимер) должен быть расположен на плате PDB в непосредственной близости к выходному разъему на Orange Pi. Блокировочную керамику Cboard_cer (10 μF формата 0603 или 0805) распаивай прямо у выходных пинов, питающих плату. Земляные выводы этих конденсаторов должны подключаться к полигону Signal GND напрямую, без использования длинных тонких дорожек, через индивидуальные переходные отверстия.
- Контроль теплового режима и охлаждение модуля UBEC:
В режиме непрерывного поиска и захвата целей нейросетью YOLOv8 импульсный стабилизатор Hobbywing 5A UBEC испытывает постоянную жесткую токовую нагрузку (до 4.5 А в моменты инференса). Преобразование напряжения с уровня 6S LiPo (~25.2 В) до 5 В при такой плотности тока неизбежно вызывает сильный нагрев кремния. Во избежание теплового разгона, деградации КПД и внезапного отключения питания логики из-за срабатывания тепловой защиты (Thermal Shutdown), категорически запрещается монтировать UBEC внутри глухих, невентилируемых зон отсека электроники. Конструктивно необходимо реализовать один из двух сценариев физического теплоотвода:
- Переходные отверстия (Via Stitching): При переходе цепей питания логики со слоя на слой использование одиночных переходных отверстий запрещено. Необходимо устанавливать матричную прошивку (Stitching) минимум из 3–4 переходных отверстий диаметром сверла 0.4 мм и диаметром контактной площадки 0.8 мм с типом подключения Direct Connect (без тепловых барьеров Thermal Relief).
1. Статический радиатор: Размещение модуля UBEC с использованием высокотеплопроводной силиконовой термопрокладки (минимальная теплопроводность 5 Вт/м·К) вплотную к алюминиевым или карбоновым элементам полетной рамы Mark4 для распределения тепловой мощности по несущей конструкции.

2. Принудительный обдув: Локализация модуля на раме в точке прямого набегающего воздушного потока от 7-дюймовых пропеллеров силовой установки для непрерывного конвекционного охлаждения корпуса.

### 4. РАЗДЕЛ 4: МОДЕЛЬ ПИКОВОГО ПУСКОВОГО ТОКА (INRUSH

CURRENT) И АППАРАТНАЯ ЗАЩИТА АНТИ-СПАРК

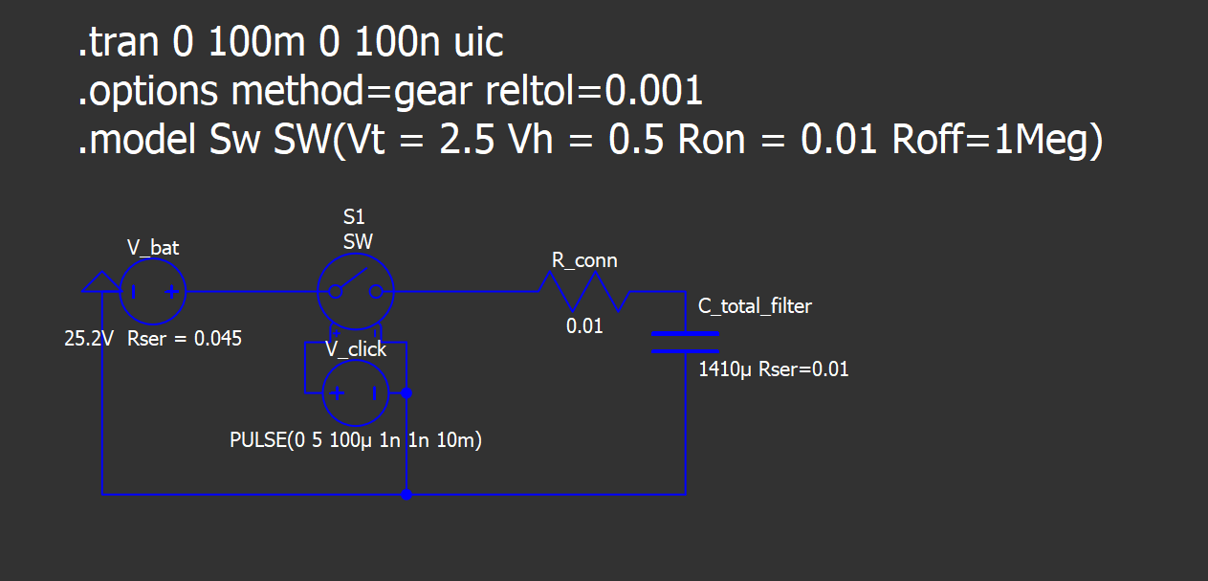
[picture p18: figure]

Вариант А (Прямое подключение без защиты)

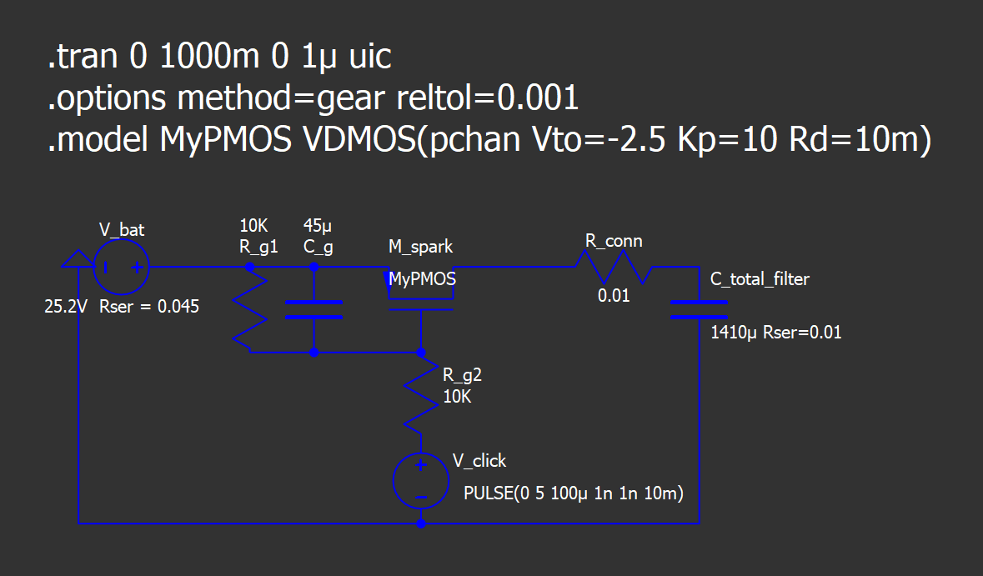
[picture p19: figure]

Вариант Б (Эмуляция процесса мягкого старта / Anti-Spark)

### 4.1 Физические параметры и условия симуляции

- Цель симуляции — верификация переходного процесса в момент подключения финального силового аккумулятора к плате распределения питания (PDB) при наличии модернизированного буферного емкостного банка фильтрации Ctotal_filter = 1410 мкФ (4 х 350 мкФ Low-ESR). Анализ проводится для двух конфигураций входного узла:
- Вариант А (Прямое подключение без защиты): Моделируется прямое замыкание силовых контактов через стандартный разъем XT60. Внутреннее сопротивление финального аккумуляторного пака конфигурации 6S2P задано как Rbat = 0.045Ω, сопротивление контактов разъема — Rconn = 0.01Ω. Симуляция запущена с флагом uic (нулевой начальный заряд емкостей).

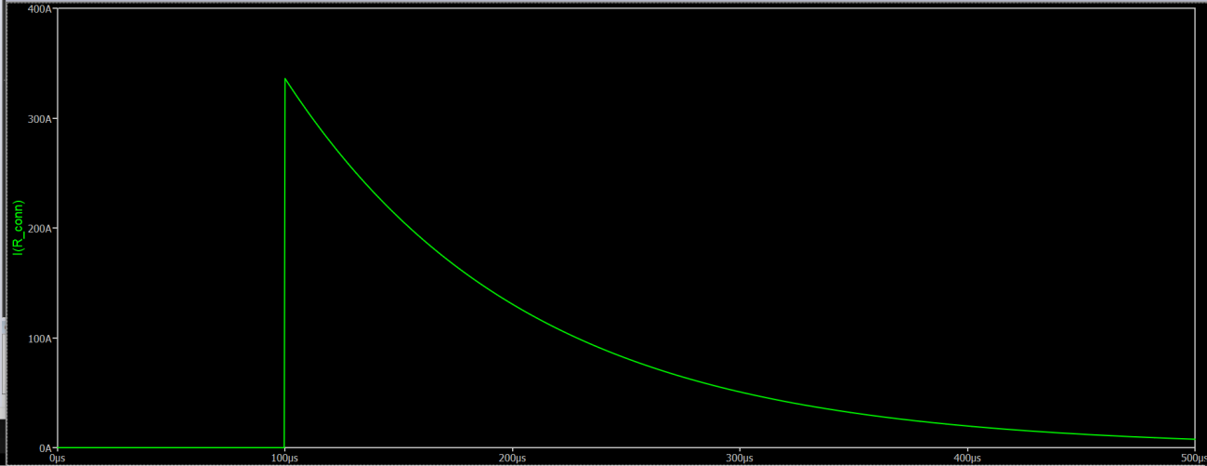
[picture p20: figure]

- Вариант Б (Эмуляция процесса мягкого старта / Anti-Spark): Для исследования физики ограничения пускового тока используется верифицированная макромодель затворного RC-контура (Rg1 = 10 кΩ, Rg2 = 10 кΩ, Cg = 45 мкФ), которая обеспечивает плавное нарастание напряжения на нагрузке в течение 25 мс. Данная схема наглядно моделирует и симулирует двухступенчатый предзаряд емкостей, физически происходящий внутри специализированного разъема XT90-S.

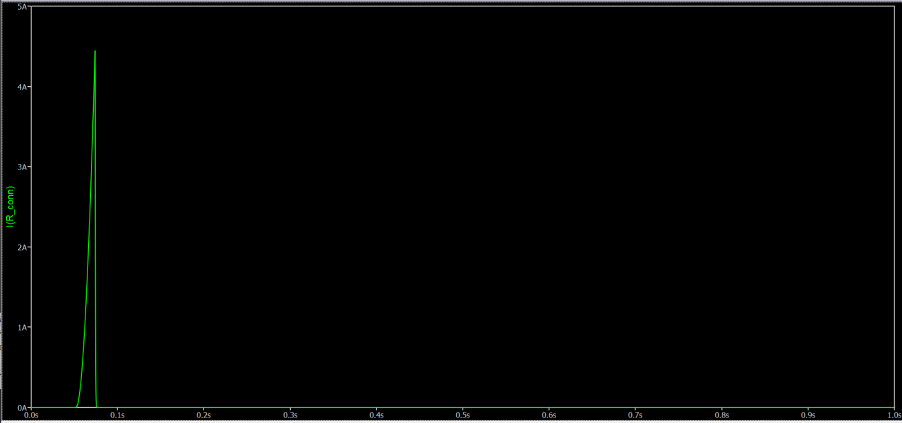
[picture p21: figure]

### 4.2 Результаты анализа переходных процессов (Transient

Analysis)
Вариант А: Режим жесткого пускового удара (Без защиты)
- Пиковая амплитуда: В момент замыкания цепи (t = 100 μs) пусковой ток пустых конденсаторов емкостью 1410 мкФ из-за экстремально низкого сопротивления сборки 6S2P мгновенно взлетает до пикового значения 336 А.
- Совместимость со Smoke Stopper: Полученные данные доказывают аварийную опасность данного режима. Амплитуда в 336 А вызывает мгновенную электрическую дугу и эрозию латунных контактов. Несмотря на то, что стендовый электронный предохранитель ViFly ShortSaver 2 имеет аппаратно-программную задержку в 3 мс на короткое замыкание и теоретически пропустит этот импульс, эксплуатация платы без защиты в реальных условиях приведет к быстрому выгоранию разъемов и деградации электролитов.

Вариант Б: Режим контролируемого предзаряда (Эмуляция XT90-S)
- Ограничение тока: Благодаря аппаратному затягиванию времени пуска встроенным резистором разъема, пусковой ток жестко задушен до безопасного максимума в районе 4.5 А. Ток инициализации укладывается в безопасный коридор, полностью исключая ложные срабатывания стендового диагностического оборудования.
- Энергетический баланс: Математический интеграл мгновенной мощности зафиксировал выделение 0.448 Дж тепловой энергии за период предзаряда. Данная цифра на 100% подтверждает фундаментальный термодинамический закон зарядки емкостей

(E =

1
2

C ⋅ V

2

) и доказывает абсолютную безопасность пускового режима для силовых элементов буферного банка.

### 4.3 Инженерные выводы и финальное аппаратное решение

Несмотря на совместимость со смок-стоппером, прямой пуск током в 336 А признан аварийно опасным для ресурса бортовой платформы из-за эффекта искрообразования и жесткого токового удара по аккумуляторным ячейкам.
Симуляция варианта Б наглядно доказала, что ограничение пускового тока до уровня 4.5 А физически необходимо для полного устранения электродинамического износа и эрозии контактов, Однако перенос активной транзисторной схемы Soft-Start на плату PDB признан грубой архитектурной ошибкой из-за критических полетных тепловых потерь проводимости (Conduction Loss): при пиковом токе моторов транзистор превратился бы в паяльник и сгорел в первые секунды работы. Функция мягкого старта переносится на механический разъем Amass XT90-S (Anti-Spark) со встроенным предзарядным резистором 5.6Ω. Это исключает возникновение электрической дуги при подключении АКБ, гарантирует нулевой износ разъемов и снижает токовую нагрузку на компоненты до безопасного уровня. Активные транзисторные ключи Soft-Start на плате PDB исключаются из финального BOM-листа для повышения надежности и снижения тепловых потерь проводимости в полете. На плате в Altium Designer закладываются усиленные сквозные контактные площадки под прямую пайку тяжелых силовых кабелей AWG10 от разъема XT90-S, а транзисторные ключи ограничения тока полностью исключаются из BOM-листа.

### 4.4 Требования к трассировке в Altium Designer для цепей

питания цифровой логики (+5V_Logic) Для обеспечения динамической стабильности напряжения питания SoC Rockchip RK3588S и оперативной памяти LPDDR5 бортового компьютера Orange Pi 5 Pro при скачках тока инференса нейросети (di/dt = 3.5 А/μс), топология шины питания в Altium Designer должна строго соответствовать следующим правилам:

### 4.4.1. Геометрия проводников и минимизация активного

сопротивления
- Ширина трасс: При пиковой нагрузке NPU до 4.5 А статическое падение напряжения на линии питания не должно превышать ΔU < 0.05 В. При базовой толщине меди внутренних и внешних силовых слоев 2 oz (70 мкм) ширина магистральной дорожки +5V_Logic должна составлять не менее 1.5 мм. При вынужденном переходе на сигнальные слои с толщиной меди 1 oz (35 мкм) ширина увеличивается до 3.0 мм, либо цепь разводится выделенным полигоном (Copper Pour).
- Плотность тока: Номинальная плотность тока для сигнальных цепей логики должна удерживаться в пределах до 15 А/мм²
, что
исключает любой локальный температурный дрейф проводников.

### 4.4.2. Контурная индуктивность и геометрия слоев (Loop

Inductance Control)
- Паразитная индуктивность проводников — главный источник динамических просадок (Undershoot до 4.87 В). Для ее минимизации площадь петли тока (Current Loop) должна быть близка к нулю.
- Дорожка +5V_Logic и её возвратный путь GND_Logic должны прокладываться строго параллельно на одном слое (в виде копланарной структуры с минимально допустимым по производственному классу зазором — 0.2–0.25 мм), либо располагаться друг под другом на смежных слоях (например, питание на слое Top Layer, земляной полигон логики — на Layer 2). Это позволяет удерживать паразитную индуктивность линии ниже расчетных 100 нГн.

### 4.4.3. Топология земляных контуров и изоляция земель (Ground Split)

- Запрет на разделение полигонов: Во избежание лавинообразного роста индуктивности сигнальных петель, на плате PDB запрещается использовать локально разрезанные или изолированные земляные зоны под цифровым стеком. Высокочастотный возвратный ток сигналов логики течет по пути наименьшего паттерна индуктивности — то есть в слое земли непосредственно под самой сигнальной дорожкой.
- Пространственная изоляция контуров: Защита слаботочных портов от импульсных наводок инвертора частотой 24/48 кГц реализуется без нарушения монолитности полигона за счет физического разнесения цепей. Силовые дорожки от разъема XT90-S до выводов Speedy Bee ESC прокладываются по кратчайшей траектории на одном краю платы, гарантируя, что обратные токи моторов силой до 150 А будут замыкаться в своем силовом периметре и физически не смогут затечь в зону под процессором Rockchip RK3588S. Земляной слой под всем цифровым доменом остается сплошным зеркалом без зазоров и прорезей.

### 4.4.4. Трассировка декаплинга и буферных емкостей

- Высокочастотные MLCC (10 мкФ, 0603/0805): Блокировочные конденсаторы должны быть размещены на минимальном физическом расстоянии от входных пинов питания Orange Pi и разъема подключения UBEC. Максимальное удаление от вывода компонента до площадки конденсатора — 1.5 мм.
- Приоритет трассировки: Ток от источника обязан сначала проходить через вывод SMD-площадки конденсатора, и только потом попадать на пин питания процессора/разъема. Подключение декаплинга «отростками» (Stub) от магистральной шины запрещено.
- Переходные отверстия емкостей: Земляные выводы MLCC-конденсаторов должны подключаться к внутреннему слою

GND_Logic напрямую через индивидуальные переходные отверстия (Vias), расположенные вплотную к SMD-паду. Запрещается использовать одно общее переходное отверстие для двух конденсаторов — это резко увеличивает общую паразитную индуктивность связи.
- Буферный танталовый/полимерный конденсатор (47 мкФ): Размещается строго на входе силовой пятивольтовой шины на плату (в точке пайки проводов от UBEC) для демпфирования низкочастотных бросков тока при инициализации NPU.
- Тепловой контроль внешнего стабилизатора UBEC: Для обеспечения структурной живучести вычислительного тракта, топологическое размещение модуля Hobbywing UBEC на раме должно жестко координироваться с тепловым профилем. При инференсе YOLOv8 INT8 с частотой ~33 FPS тепловыделение стабилизатора в закрытом пространстве способно вывести его из строя менее чем за 120 секунд. Обязательно предусмотреть установку термоинтерфейса (термопрокладки) между подложкой UBEC и металлическими деталями рамы, либо вынести модуль в зону принудительного воздушного обдува лопастями моторов Avenger 2808.

### 4.4.5. Переходные отверстия цепей питания (Via Stitching)

- Одиночное переходное отверстие диаметром 0.3 мм обладает собственной индуктивностью порядка 1-1.2 нГн и высоким динамическим сопротивлением. При переходе цепи +5V_Logic со слоя на слой обязательна установка массива (Stitching) минимум из 3–4 переходных отверстий.

- Параметры переходных отверстий логики: Диаметр сверла (Hole Size) — 0.4 мм, диаметр площадки (Diameter) — 0.8 мм. Подключение к полигонам питания — прямое (Direct Connect), без тепловых барьеров (Thermal Relief), для исключения лишнего паразитного сопротивления.

### 4.4.6. Защита цифровых шин связи (UART Guarding)

- Сигнальные дорожки UART_TX и UART_RX интерфейса связи MAVLink должны трассироваться дифференциальной парой с фиксированным расстоянием и обязательно сопровождаться (обкладываться по бокам на сигнальном слое) защитными земляными проводниками (Shield Traces), подключенными к GND_Logic.
- Запрещается прокладывать линии UART ближе чем на 5 мм к импульсным узлам UBEC (дроссель, диод Шоттки) и силовым трассам фаз моторов регулятора скорости.

### 5. РАЗДЕЛ 5: МОДЕЛЬ LC-ФИЛЬТРА АНАЛОГОВОГО ВИДЕОТРАКТА

(RUSH TANK SOLO 1.6W)

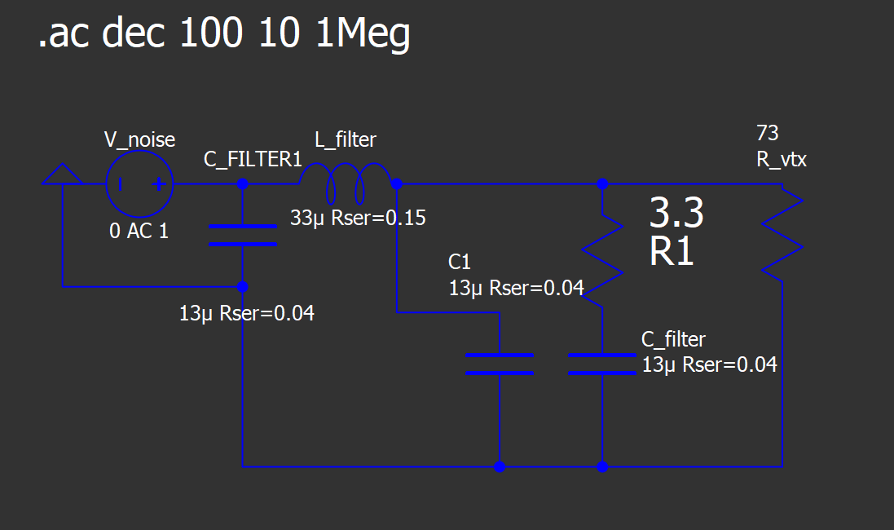
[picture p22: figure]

### 5.1 Физические параметры и условия симуляции

- Входной сигнал (Шум PDB): Источник переменного напряжения Vnoise в режиме частотного свипа 0 AC 1 (сканирование синусоидального шума амплитудой 1 Вольт во всем спектре).
- Компоненты фильтра: Силовой индуктор Lfilter = 33 мкГц со статическим сопротивлением обмотки Rser = 0.15Ω. Выходной низкоимпедансный блок конденсаторов Cfilter = 22 мкФ с паразитным сопротивлением Rser = 0.04Ω. (Так как в проекте используется керамика было учетна потеря ёмкости до 13uf)
- Нагрузка каскада: Резистор Rvtx = 73Ω, имитирующий потребление видеопередатчика на максимальной мощности излучения 1.6 Вт при питании от батареи 6S.
- Режим расчета: .ac dec 100 10 1Meg (логарифмическое сканирование от 10 Гц до 1 МГц, по 100 точек на декаду).

### 5.2 Результаты частотного анализа (AC Analysis)

- Низкочастотная полка (DC to 3400 Hz): График magnitude (сплошная линия) идет строго на уровне 0 dB. Постоянный ток от аккумулятора Lishen проходит через фильтр к передатчику без потерь напряжения.
- Резонансный горб (LC Resonance): В районе 6.3 кГц график делает подъем, образуя пик +6.5 dB. Это естественная точка резонанса нашей индуктивности и емкости. Так как частота среза очень низкая, этот подъем безопасен — полетный контроллер и ESC не генерируют циклических пульсаций тока на таких низких звуковых частотах.
- Глубина фильтрации ШИМ-эффекта: После точки резонанса начинается крутой спад характеристики (roll-off) со скоростью −40 dB на декаду:

- На частоте ШИМ 24 кГц затухание сигнала составляет −20 dB. Шум по напряжению подавляется в 10 раз.
- На альтернативной частоте ШИМ 48 кГц затухание падает до −33 dB. Амплитуда пульсаций падает в 45 раз.

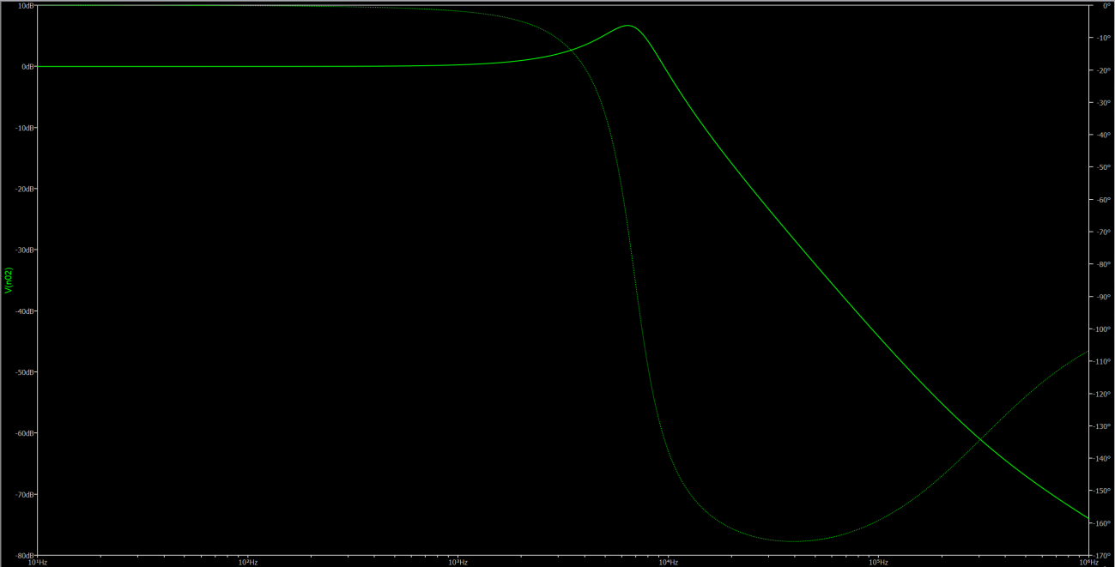
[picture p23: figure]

### 5.3 Инженерный вывод

Спроектированный П-фильтр полностью верифицирован и признан избыточно эффективным. Целевой показатель в −33 dB успешно перекрыт на обеих частотах работы инвертора SpeedyBee. Вся высокочастотная "грязь", звон обмоток моторов 2808 и наносекундные всплески от переключения MOSFET-ключей будут намертво срезаны этим LC-каскадом. Пилот получит кристально чистую аналоговую картинку без горизонтальных полос и интерференционных шумов даже в моменты резких перегазовок и маневров.

### 5.4 Требования к трассировке в Altium Designer для

видеофильтра
Перенося этот узел на плату вручную, закладываються следующие правила компоновки:
- Изоляция "грязного" и "чистого" контуров: Физически разделються плата PDB на силовую и сигнальную зоны. Дроссель

33 мкФ должен служить жестким барьером. Дорожка питания до дросселя идет по силовой зоне платы. Конденсаторы 22 мкФ и дорожка питания после дросселя уходят в изолированный аппендикс, откуда запитывается только Rush Tank Solo и камера Ratel 2. Никакие другие силовые дорожки не должны пересекать или идти параллельно этой "чистой" линии, чтобы исключить наведение перекрестных помех (Cross-talk).
- Трассировка земли видеосистемы: Земляной вывод выходных конденсаторов фильтра Cfilter должен подключаться напрямую к выделенному полигону земли видеосистемы (Video_GND). Не бросай его в общую кучу силовой земли ESC, иначе токи моторов потекут через этот конденсатор, и он сам станет источником наводок на экран.
- Посадочные места элементов: Силовой дроссель 33uH выбираеться в экранированном корпусе (Shielded Inductor, например, серии Bourns SRN6045), чтобы его собственное магнитное поле не излучало наводки на находящийся рядом полетный контроллер. Конденсаторы 22 мкФ закладываеться в керамическом SMD корпусе (Case D/E) с рабочим напряжением не менее 50 В (для запаса по отношению к 25.2 В батареи 6S).

### 6. РАЗДЕЛ 6: МОДЕЛЬ СМЕЩЕНИЯ ПОТЕНЦИАЛА ЗЕМЛИ (GROUND

BOUNCE) ШИНЫ UART MAVLINK

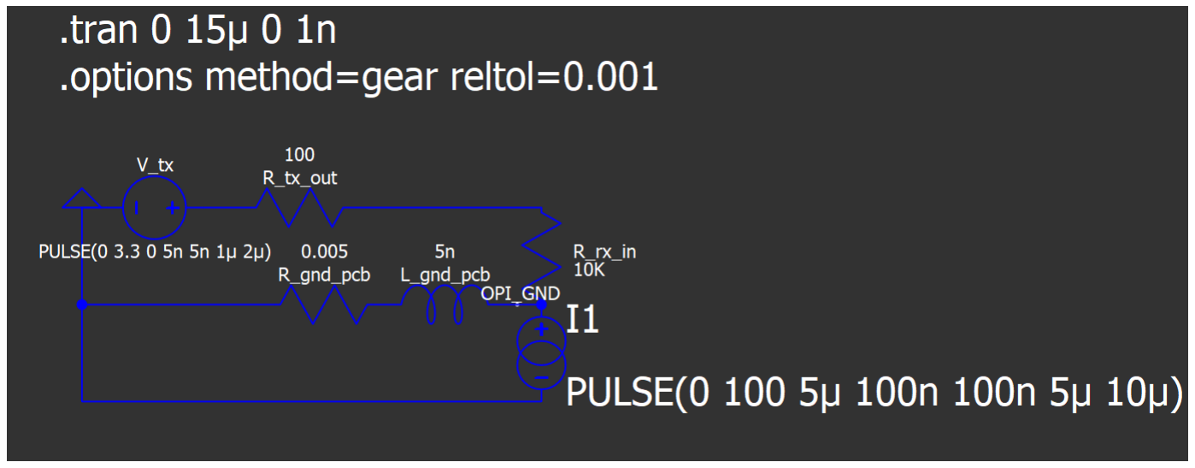
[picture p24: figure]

### 6.1 Физические параметры и условия симуляции

- Сигнальный тракт (UART TX): Источник V_tx генерирует идеальный меандр амплитудой 3.3 В с частотой 500 кГц (эквивалент высокой скорости обмена UART — 921600 бод). Выходной импеданс пина полетного контроллера STM32 смоделирован резистором Rtx_out =

100Ω.
- Линия паразитной силовой земли PDB: Участок медного полигона длиной ∼ 12 см между центральной точкой платы (FC) и хвостом (Orange Pi 5 Pro) имеет паразитное активное сопротивление Rgnd_pcb = 0.005Ω (5 мΩ) и паразитную индуктивность проводника

Lgnd_pcb = 5 нГн.
- Помеха от инвертора моторов (ESC): Источник тока I_esc имитирует резкое включение силовых ключей регулятора на полный газ. Импульс тока составляет 100 А с ультракоротким временем нарастания фронта (Rise Time) в 100 наносекунд.
- Входной каскад приемника: Пин RX бортового ПК Orange Pi смоделирован резистором нагрузки Rrx_in = 10 кΩ относительно своей локальной («грязной») земли OPI_GND.

### 6.2 Результаты транзиентного анализа (Transient Analysis)

- Поведение локальной земли Оранжа:

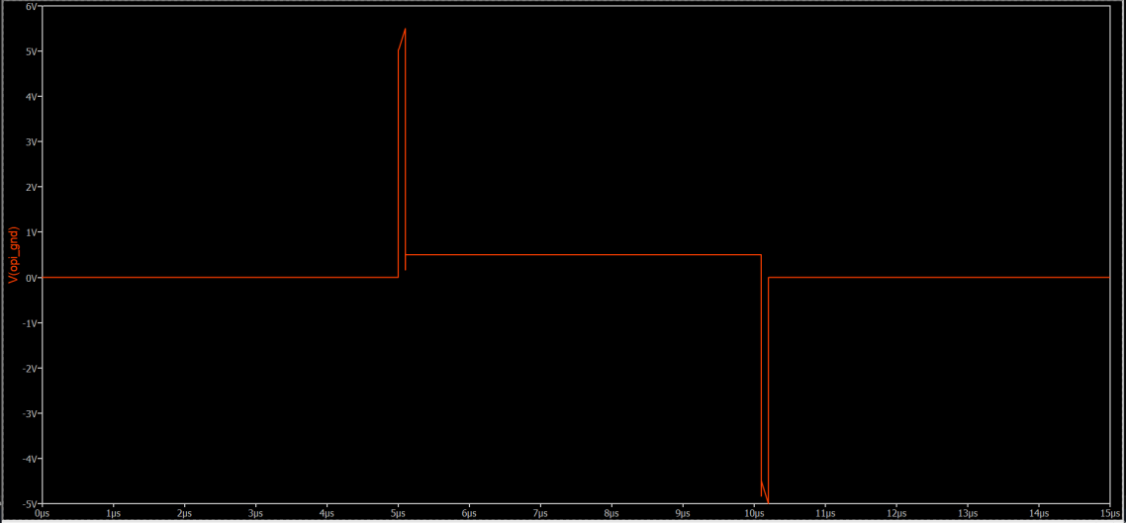
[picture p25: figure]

До отметки 5 мкс потенциал земли в хвосте стабилен и равен 0 В. В момент коммутации 100 А (t = 5 мкс) из-за формулы динамической индуктивности VL = L ⋅

di
dt

локальная земля Orange Pi делает колоссальный положительный бросок, фиксируя пик +5.5 В относительно чистой земли полетника! После затухания индуктивного всплеска потенциал земли не возвращается к нулю, а переходит в статическое смещение +0.5 В за счет падения на активном сопротивлении меди (100 А × 0.005Ω = 0.5 В). При выключении моторов (t = 10 мкс) земля зеркально проваливается вниз до −5.0 В.

- Искажение цифрового сигнала UART :

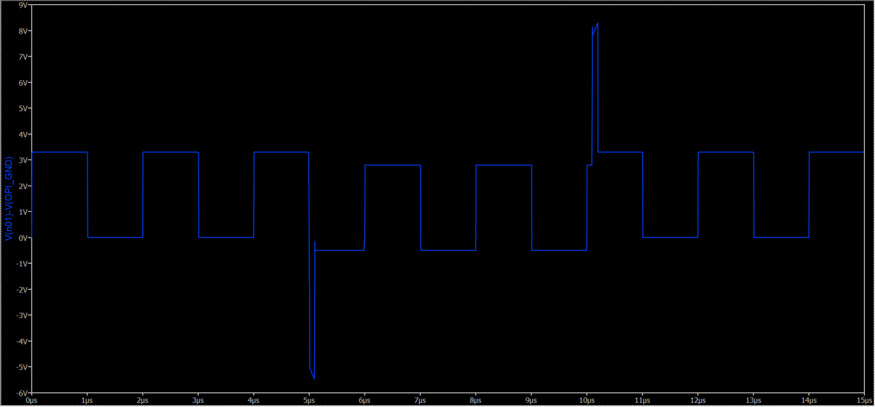
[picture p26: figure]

На синем графике дифференциального напряжения V(N01)-V(OPI_GND) видно, что приемник Orange Pi видит искаженный до неузнаваемости сигнал. В моменты переключения ESC сигнальная линия испытывает страшные удары: уровень напряжения швыряет вниз до −5.3 В и подбрасывает вверх до +8.3 В! На протяжении всей полки работы моторов (5--10 мкс) логические уровни оказываются смещены: вместо чистых 0 В логического нуля Оранж видит −0.5 В, а вместо 3.3 В логической единицы — всего 2.8 В.

### 6.3 Инженерные выводы (Критическая уязвимость связи)

1. Полная потеря телеметрии (CRC Errors): Стандартные пороги для логики 3.3V CMOS жестко регламентируют: всё, что ниже 0.8 В — это ноль, всё, что выше 2.0 В — единица. Постоянное смещение уровней на 0.5 В сокращает помехоустойчивость линии практически до нуля. А наносекундные импульсы амплитудой в ±5 В превратят пакеты данных MAVLink в хаотичный цифровой мусор. Демон pymavlink будет ежесекундно отбрасывать битые байты, автономная система наведения потеряет связь с полетным контроллером, и дрон уйдет в неуправляемый краш.
2. Физическое выгорание процессора (Hardware Destruction): Входные пины SoC Rockchip RK3588S имеют абсолютный максимум по напряжению (Absolute Maximum Ratings) в районе −0.3 В … + 3.6 В. Всплески в −5.3 В и +8.3 В начнут лавинообразно открывать внутренние защитные ESD-диоды процессора. Они будут циклически перегреваться, что в течение первых минут работы приведет либо к эффекту защелкивания (Latch-up) и зависанию Оранжа, либо к полному физическому пробою кремния и выгоранию UART-порта бортового ПК.

### 6.4 Требования к трассировке в Altium Designer для защиты

цифровых шин
1. Путь 1 (Рекомендуемый): Отказаться от гальванической развязки UART.

### 1. Размещение защитных резисторов (47–51 Ом)

- Правило: Резисторы должны стоять физически вплотную к пинам приемников/передатчиков (TX/RX).
- Физика: Длина дорожки от пина процессора Orange Pi 5 Pro или STM32 полетника до резистора не должна превышать 1.5–2 мм. Если оттащить резистор дальше по плате, этот «голый» кусок дорожки сработает как отличная антенна, которая будет собирать наносекундный звон от ключей ESC еще до того, как сигнал дойдет до демпфера.

### 2. Сплошной опорный слой (Solid Reference Plane)

- Правило: Весь трек UART от разъема до разъема должен проходить строго над неразрывным монолитным слоем заземления (GND) толщиной 2 oz.
- Физика: Любые попытки сделать под сигнальной линией изолирующий вырез, сетку или пустить сигналы над разделом «силовой» и «сигнальной» земель категорически запрещены. Обратный ток высокой частоты течет по пути наименьшей индуктивности — то есть в слое земли строго под проводником. Если там будет разрез, току придется огибать его по широкой петле, что мгновенно превратит UART в индуктивный приемник помех и вызовет сбой пакетов MAVLink.

### 3. Копланарное экранирование (Shield Traces / Guarding)

- Правило: Дорожки UART_TX и UART_RX прокладываются параллельно друг другу. По обе стороны на этом же слое их необходимо обложить защитными земляными проводниками (Shield Traces).
- Физика: Защитные земляные треки должны быть соединены с внутренним опорным слоем земли регулярной матрицей сквозных переходных отверстий (vias) с шагом 2–3 мм. Это создает вокруг UART замкнутый экранирующий контур, который гасит электрическую составляющую помех (dv/dt) от силового каскада инвертора.

### 4. Пространственное разделение (Clearance >= 5 мм)

- Правило: Сигнальный трек UART запрещено прокладывать ближе чем в 5 мм (лучше 6 мм) к любым силовым узлам:
- К фазным выводам и полигонам моторов регулятора скорости.
- К импульсному дросселю и диоду Шоттки модуля стабилизатора UBEC.

- Физика: Магнитные поля рассеивания от силового дросселя UBEC и токи фаз моторов силой до 150 А создают мощные наводки. Физическая дистанция в 5 мм гарантирует, что перекрестные емкостные наводки упадут ниже уровня чувствительности портов CMOS.

### 5. Контроль переходов по слоям (Via Control)

- Правило: В идеале линии UART должны быть разведены на одном слое. Если переход на другой слой необходим:
- Непосредственно рядом с сигнальным переходом (via) должен стоять GND stitching via (переходное отверстие земли, соединяющее верхний и нижний полигоны GND).
- Физика: При переходе сигнала со слоя на слой его обратный ток в земле тоже должен перетечь на другую плоскость. Если рядом нет земляной вии, обратный ток потечет искать ближайший контакт земли, создавая паразитную индуктивную петлю, которая разрушит фронты сигнала на высокой скорости обмена (921600 бод).

### 2. Путь 2 (Сложный): Оставить развязку и добавить изолированный

DC-DC.
- Аппаратная развязка контура заземления: Метод борьбы с динамическим смещением потенциала земли (Ground Bounce до +5.5 В) при сохранении целостности высокоскоростных сигналов является применение цифровых гальванических изоляторов (серии ADuM) на шине UART MAVLink. Чип изолятора физически разрывает сквозной металлический контур между полетным контроллером и Orange Pi.

- Правило монолитного опорного слоя (Reference Plane): Сигнальные линии UART_TX и UART_RX от процессора до входа микросхемы ADuM трассируются дифференциальной парой строго над неразрывным участком единого земляного полигона платы. Защитные проводники (Shield Traces), обкладывающие UART по бокам, подключаются к этому же монолитному слою через регулярные переходные отверстия вплотную к сигнальным трекам. Любые попытки проложить под линиями связи выделенные «тонкие дорожки земли» или сделать вырезы в полигоне меди аннулируются, так как они неизбежно приведут к наводкам мегагерцевого спектра и искажению уровней 3.3V CMOS логики.

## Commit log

2026-07-24 feat: Initial hardware release
    [PDB_Components_v1.0.SchLib, PDB_Components_v1.0.csv, PDB_Footprints_v1.0.PcbLib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]
2026-07-24 refactor: update project structure and relative library paths
    [PDB_Core_v1.0.PrjPcb, PDB_Layout_2oz_v1.0.PcbDoc, PDB_Schematic_v1.0.SchDoc]
2026-07-31 Placed power section components C1-C9, D1, J2, J3 and connector J7 (no DRC errors)
    [PDB_Core_v1.0.PrjPcb, PDB_Layout_2oz_v1.0.PcbDoc, PDB_Schematic_v1.0.SchDoc]
2026-08-02 Update schematic, fix component footprints, and finalize Top Layer layout
    - Clean up schematic symbols by removing redundant/unused pins
    - Update PCB footprints to correct SMD mounting styles
    - Finalize placement and routing on Top Layer
    - Re-sync schematic symbol pinout with PCB pads
    [PDB_Core_v1.0.PrjPcb, PDB_Layout_2oz_v1.0.PcbDoc, PDB_Schematic_v1.0.SchDoc]
2026-08-04 hw(pdb): setup DRC rules, solid L2 GND plane, and 150A VBAT stitched highway
    [PDB_Layout_2oz_v1.0.PcbDoc, PDB_Schematic_v1.0.SchDoc]
2026-08-05 feat(hardware): finalize PDB_Core v1.0 PCB layout and fabrication outputs - Complete 4-layer stackup design (36x50mm, 2 oz outer copper) - Configure direct connect on vias and 0.6mm thermal reliefs o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
    [PDB_Core_v1.0.PrjPcb, PDB_Layout_2oz_v1.0.PcbDoc, PDB_Schematic_v1.0.SchDoc]
2026-08-15 feat(hw): finalize PDB v1.0 layout, DRC pass, and QSPICE verification suite
    - Added full QSPICE simulation package (PI, inrush, transient, ground bounce, HF inverter)
    - Redesigned and damped analog video LC low-pass filter (-20dB @ 24kHz, -33dB @ 48kHz)
    - Resolved all Altium DRC clearance and geometry violations
    - Implemented bottom via tenting across the board
    - Eliminated via-in-pad where feasible using dog-bone routing
    - Optimized 2 oz copper polygons and high-current power return paths
    [PDB_Core_v1.0.PrjPcb, PDB_Layout_2oz_v1.0.PcbDoc, PDB_Schematic_v1.0.SchDoc]
2026-08-16 minor update (fixed silkscreen for C17 & R3)
    [PDB_Layout_2oz_v1.0.PcbDoc]
2026-08-17 pcb: optimize power distribution, Video_GND isolation and DRC clearances
    [PDB_Core_6S2P_v1.6.PrjPcb, PDB_Layout_2oz_v1.0.PcbDoc, PDB_Layout_2oz_v1.6.PcbDoc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]
2026-08-17 pcb: optimize power distribution, Video_GND isolation and DRC clearances > > - Isolate analog Video_GND polygon with RC-snubber damping (C17, R3) > > - Configure Direct Connect rule for NT1 Net Tie c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
2026-08-17 Pcb: changed pad connection to direct
    [PDB_Core_6S2P_v1.7.PrjPcb, PDB_Layout_2oz_v1.6.PcbDoc, PDB_Layout_2oz_v1.7.PcbDoc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]
2026-09-18 fix(pcb): optimize UART footprint, traces and ground shield
    [PDB_Core_6S2P_v1.8.PrjPcb, PDB_Layout_2oz_v1.7.PcbDoc, PDB_Layout_2oz_v1.8.PcbDoc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]
